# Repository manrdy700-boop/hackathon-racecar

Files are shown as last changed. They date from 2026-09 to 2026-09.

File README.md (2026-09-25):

# hackathon-racecar 🏆

北邮 & 中大四天三夜赛车黑客松（2026-08-26 ~ 08-29）**冠军车**的机械设计资料。

3D 打印底盘 + STM32 电控 + FPV 第一视角驾驶的迷你竞速车。四天内完成建模 → 打印 →
装配 → 调试 → 比赛全流程，最终在决赛夺冠（车手即本仓库作者）。

*Championship-winning mini FPV race car from a 4-day hackathon — mechanical design
files, printable STLs, gear-train calculators and build documentation. (Docs in Chinese.)*

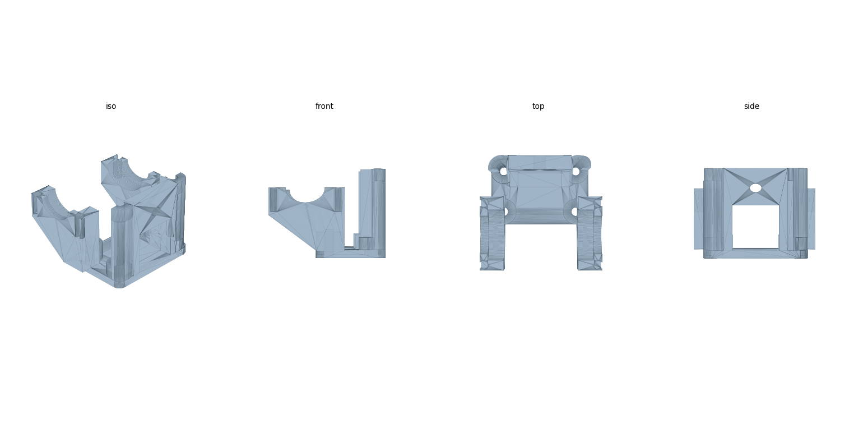
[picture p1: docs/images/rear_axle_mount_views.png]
后轴承座四视图


## 仓库内容

| 目录 | 内容 |
|---|---|
| `stl/` | 全套可打印 STL：前桥、后桥、轮辐盘（见下方零件清单） |
| `docs/机械结构说明书.pdf` | 差速器 / 传动 / 悬挂三大系统的原理与装配说明（含矢量示意图） |
| `docs/team/` | 团队文档模板：分工表、每日调试日志、赛道测试与调参记录、道具赛机制设计、差速器装配流程 |
| `tools/` | 齿轮传动计算器（Python）与说明书 PDF 生成脚本 |

## 零件清单

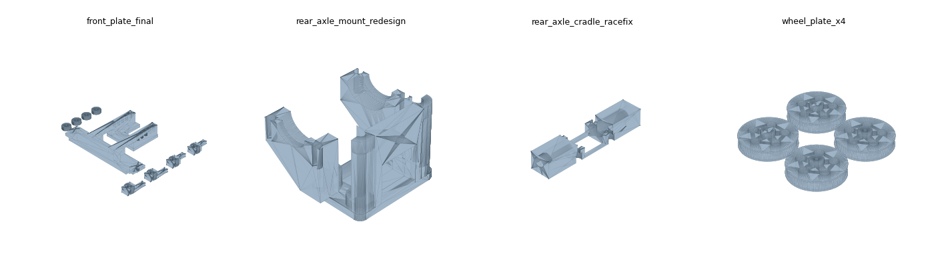
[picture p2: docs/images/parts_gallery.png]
零件总览


| 文件 | 说明 |
|---|---|
| `front_plate_final_0828.stl` | **前桥打印板（最终定稿版）**：主框架 + 转向节 + 轮毂盘，刚性结构 + 顶丝锁 + 销槽转向 |
| `rear_axle_mount_redesign.stl` | **后轴承座（重设计版）**：半圆轴承窝 + 侧导轨 |
| `rear_axle_cradle_racefix.stl` | 后轴托架 —— 比赛日凌晨 2:10 的抢修件，赛场应急设计的纪念 |
| `wheel_plate_x4.stl` | 轮辐盘 ×4 打印板 |
| `iterations/` | 被最终版取代的历史迭代（前桥 v1/v5、后轴承座旧版），保留供参考设计演进 |

打印参数：PLA，所有孔按名义尺寸 +0.25 mm 补偿设计（宁松勿紧，松了用顶丝锁）。

## 关键设计参数

| 项目 | 数值 |
|---|---|
| 齿轮模数 | 0.5 |
| 传动方案 | 单级减速，电机 8T 小齿 → 差速器 29T 盘齿 |
| 传动比 | 3.625（中心距 9.25 mm） |
| 车轮直径 | 28.14 mm |
| 理论极速 | ≈ 5.3 m/s (19 km/h) |
| 电机 | 有刷 13000 rpm / 28 g·cm / 7.0 V |
| 打印孔径补偿 | 名义尺寸 +0.25 mm（PLA，宁松勿紧，松了用顶丝锁） |

## 齿轮计算器用法

```bash
# 双联齿轮多级传动链：极速 / 加速度 / 每级中心距 / 编码器换算
python tools/gear_train.py --pinion 8 10 --compound 30:9 --final 29 --wheel 28.14

# 独立齿轮两两啮合的单级/两级方案枚举
python tools/gear_calc.py --tip-dia 15 16 9 17 --wheel 28.14
```

计算器会按「分度圆 d = m·z、中心距 a = m(z₁+z₂)/2」把齿数配对换算成整车极速、
起步加速度和建模打孔用的中心距，并给出室内小赛道的可用性判断。

## 经验教训（写给下一届）

- **打印队列是全营最大的瓶颈**——Day1 晚上必须交出切片，建模宁可保守也别返工
- **卡尺量到的是齿顶圆不是分度圆**，差 2 个齿 = 0.5 mm 中心距误差，足以卡死；数齿数核对
- **所有孔画名义 +0.25 mm**，锚点选前后轮毂；松了可以顶丝锁，紧了只能重打
- **耐力赛强制换胎** → 快拆车轮机构在 Day1 建模时就要设计进去
- 红外计时传感器和图传天线必须装车顶朝正上方，被车壳挡住就计不了圈

## 说明

- 车端固件基于主办方提供的 GT_Car 模板（STM32F103RCT6 + FreeRTOS）开发，
  模板版权归主办方，故固件代码不在本仓库内；本仓库仅包含我们自己的设计产出。
- SolidWorks 源文件由队友持有，本仓库提供打印用 STL。

## License

[MIT](LICENSE) — 随意使用、修改、商用，保留署名即可。

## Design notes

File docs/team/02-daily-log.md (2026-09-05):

# 每日调试日志

> 评分占比 10% 的「过程复盘与文档」主要看这份。每天收工前花 10 分钟填完，
> 不要攒到最后一天补——补出来的日志一眼就能看出来，而且真正的技术细节那时已经忘了。
>
> **填写要点**：问题记录写「现象 → 怎么定位 → 根因 → 怎么解决」，
> 不要只写「电机不转，后来好了」。根因那一栏是最值钱的，结营答辩和报告全靠它。

---

## Day1（8/26）理论认知 + 3D 建模设计

**当日目标**：出无干涉三维模型 → 切片 → 进打印队列；确定分工；搭好开发环境

| 时段 | 计划 | 实际完成 | 状态 |
|---|---|---|---|
| 09:00-09:40 | 开营宣讲 | | ☐ |
| 09:50-12:00 | 基础理论授课 | | ☐ |
| 14:00-18:00 | SolidWorks 建模 | | ☐ |
| 19:00-22:00 | 导出 STL / 切片 / 提交打印 | | ☐ |

**硬性产出物**

- ☐ 无干涉 SolidWorks 三维底盘模型
- ☐ 打印切片文件（含参数：层高 ___ / 填充率 ___ / 壁厚 ___ / 支撑 ___）
- ☐ 小组分工表
- ☐ 手绘整车电路接线草图
- ☐ 开发环境搭好，GT_TEST 能编译出 hex

**向主办方确认的问题与答复**

| 问题 | 答复 | 影响 |
|---|---|---|
| 车轮/轮胎从哪来？耐力赛的「胎」是什么 | | |
| 3D 打印机型号 / 台数 / 每组配额 | | |
| 红外传感器 + 图传天线尺寸与安装方式 | | |
| 电池规格 / 充电器 | | |
| 电机驱动芯片型号 | | |
| 编码器线数 | | |
| 方向盘可用按键 → 协议字段映射 | | |

**问题记录**

| # | 现象 | 定位过程 | 根因 | 解决方案 | 耗时 |
|---|---|---|---|---|---|
| 1 | | | | | |
| 2 | | | | | |

**当日复盘**

- 做得好的：
- 出问题的：
- 建模缺陷 / 次日修改方案：

**明日计划**：

---

## Day2（8/27）机械装配 + 硬件接线

**当日目标**：整车装配完成；接线无短路；电机与舵机能单独动起来

| 时段 | 计划 | 实际完成 | 状态 |
|---|---|---|---|
| 08:30-10:00 | 打印件取件、打磨修边 | | ☐ |
| 10:00-14:00 | 整车机械组装 | | ☐ |
| 14:00-18:00 | 电控硬件接线 | | ☐ |
| 19:00-23:00 | 环境搭建 + 分模块调试 | | ☐ |

**硬性产出物**

- ☐ 完整装配的机械整车
- ☐ 标准化电路接线图
- ☐ 电机/舵机单模块调试代码（可运行）
- ☐ 跨小组互查机械结构与电路隐患（互查组：____）

**上电前安全检查**（PPT 明确要求，每次上电都要走一遍）

- ☐ 电池正负极正确
- ☐ 板上无锡球、无导体杂质
- ☐ 无机械卡死 / 堵转
- ☐ 万用表通断检测：电源对地不短路

**标定记录**（数值同步填进 `User/Task/car_config.h`，并记到 `03-track-test-log.md`）

| 参数 | 实测值 | 怎么测的 |
|---|---|---|
| `MOTOR_DEADZONE` | | 车架空，油门从 0 慢加，记轮子刚转的 PWM |
| `MOTOR_REVERSE` | | 前进方向是否正确 |
| `SERVO_TRIM` | | 直行时车不跑偏的中位补偿 |
| `SERVO_HALF_RANGE` | | 加到轮子打满但拉杆不顶死 |
| `SERVO_REVERSE` | | 打左是否真的往左 |
| `ENCODER_DIR` | | 前进时速度是否为正 |
| `COUNTS_PER_METER` | | 推车走 1 米的总计数（推 3 次取平均） |

**问题记录**

| # | 现象 | 定位过程 | 根因 | 解决方案 | 耗时 |
|---|---|---|---|---|---|
| 1 | | | | | |
| 2 | | | | | |

**当日复盘**：

**明日计划**：

---

## Day3（8/28）整车联调 + 赛道迭代测试

**当日目标**：FPV 能开；跑完适应性路段；锁定最终调校参数

| 时段 | 计划 | 实际完成 | 状态 |
|---|---|---|---|
| 08:30-12:00 | 整车软硬件联调 + 图传 | | ☐ |
| 14:00-18:30 | 绕桩 / 起伏 / 8 字专项测试 | | ☐ |
| 19:00-24:00 | 迭代调参 + 全量故障排查 | | ☐ |

**硬性产出物**

- ☐ 整车联动控制程序
- ☐ 赛道测试记录表（见 `03-track-test-log.md`）
- ☐ 参数优化迭代日志（同上）
- ☐ **三维模型与完整控制代码已备份**（git commit + 云盘/U 盘）
- ☐ 三人都完成驾驶练习，记录各自平均圈速
- ☐ 耐力赛换胎流程演练并计时

**问题记录**

| # | 现象 | 定位过程 | 根因 | 解决方案 | 耗时 |
|---|---|---|---|---|---|
| 1 | | | | | |
| 2 | | | | | |

**当日复盘**：

**明日备战清单**：

---

## Day4（8/29）性能考核 + 竞速总决赛

**赛前检查**（每场比赛前都走一遍）

- ☐ 电池电压 > 7.4V（低于 6.6V 必须换/充）
- ☐ 图传天线、红外传感器朝正上方且无遮挡
- ☐ 螺丝无松动、结构无开裂
- ☐ 车轮无旷量、转向无卡顿
- ☐ 遥控链路正常（心跳灯慢闪 = 正常，快闪 = 失联）
- ☐ 备件与工具已带到赛道边

**成绩记录**

| 比赛 | 时间 | 成绩 | 名次 | 问题/备注 |
|---|---|---|---|---|
| 排位赛（最快单圈） | 10:00 | | | |
| 15 圈正赛 · 小组赛 | 11:00 | | | |
| 15 圈正赛 · 决赛 | | | | |
| 道具赛 · 小组赛 | 14:00 | | | |
| 道具赛 · 复活/半决/决赛 | | | | |
| 耐力赛 · 小组赛 | 15:00 | | | |
| 耐力赛 · 后续轮次 | | | | |

**结营总结要点**

- 最大的技术难点：
- 最有效的一次优化：
- 如果重来一次会怎么做：

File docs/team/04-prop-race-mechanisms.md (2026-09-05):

# 道具竞速赛 · 机制方案设计

> **规则**（PPT P9）：15 圈，可使用**最多 3 种机制**，每种**不超过 5 次**，
> 每次**不超过 3 秒**，**机制需绑定方向盘按键**。
> 说明原文：「附加题，发散思维，尽可能干扰对手 or 帮助自己」。

---

## 一、一个漂亮的对应关系

主办方的通信协议（`User/Bsp/ControlToCar.pb.h` → `CarData_Function`）里，
方向盘能下发的**布尔型按键字段正好是 3 个**：

| 协议字段 | 原设计用途 | 我们拿来做 |
|---|---|---|
| `c_signal` | 电容 / ERS 放电 | 机制 A |
| `battle_signal` | 缠斗 / DRS | 机制 B |
| `drift` | 漂移开关 | 机制 C |

**3 个 bool 按键 ↔ 规则允许的 3 种机制**，不需要改通信协议，也不需要主办方配合改地面站。
读法就是 `rc_ctrl.car_function.c_signal` 等，通信任务已经解析好了。

> ⚠️ **开营后必须确认的一件事**：方向盘上到底哪几个物理按键映射到这三个字段？
> 如果地面站现在把 `c_signal` 硬编码成 0（完整版固件的文档 §4.1 提到过这个情况），
> 那这条路就不通，要请主办方打开。**这个问题今天就要问。**

---

## 二、核心工程点：把规则写进固件

**不要靠车手手动松手来控制 3 秒。** 手一抖按成 3.2 秒就可能被判违规，
而且没人数得清用了几次。正确做法是写一个**机制管理器**，由固件强制保证：

- **上升沿触发** —— 按住不放只算一次，松开再按才是第二次
- **满 3 秒自动截断** —— 物理上不可能超时
- **每种用满 5 次后自动失效** —— 物理上不可能超次
- **冷却时间** —— 防手抖连点白白浪费次数
- **失联 / 低压时强制关闭** —— 安全兜底

这段代码本身就是很好的答辩材料：**「我们把比赛规则编译进了固件，所以我们不可能违规」**。

### 实现状态

| 机制 | 绑定按键 | 状态 |
|---|---|---|
| A · 弹射起步 Boost | `c_signal` | ✅ 已实现 (`User/Task/mech.c`) |
| B · 出弯循迹控制 TC | `battle_signal` | ✅ 已实现 (`User/Task/mech.c`) |
| C · 爆闪 / 机械挡板 | `drift` | ⏳ 次数与时长约束已生效, 输出待硬件确定 |

代码在 `User/Task/mech.c` / `mech.h`, 参数在 `car_config.h` 第 8 节。
下面保留设计说明, 便于答辩时讲清楚思路。

### 参考实现

放在 `chassis_task.c` 里，`Chassis_Loop()` 每 1ms 调用一次即可。

```c
/* ---- 道具赛机制管理器 ---- */
#define MECH_MAX_USE       5      /* 规则: 每种最多 5 次 */
#define MECH_MAX_MS     3000      /* 规则: 每次最长 3 秒 */
#define MECH_COOLDOWN_MS  500     /* 冷却, 防手抖连点浪费次数 */

typedef enum { MECH_BOOST = 0, MECH_TC, MECH_STROBE, MECH_COUNT } MechId_t;

typedef struct {
    uint8_t  active;         /* 当前是否生效 */
    uint8_t  used;           /* 已使用次数 */
    uint32_t start_tick;     /* 本次激活时刻 */
    uint32_t last_end_tick;  /* 上次结束时刻(冷却用) */
    uint8_t  key_prev;       /* 上一拍按键电平(上升沿检测用) */
} Mech_State_t;

static Mech_State_t mech[MECH_COUNT];

static void Mech_Update(MechId_t id, uint8_t key)
{
    Mech_State_t *m = &mech[id];
    uint32_t now = HAL_GetTick();

    /* 失联时一律强制关闭, 不允许任何机制残留 */
    if (rc_ctrl.RC_READY != 0)
    {
        if (m->active) { m->active = 0; m->last_end_tick = now; }
        m->key_prev = key;
        return;
    }

    if (m->active)
    {
        if (now - m->start_tick >= MECH_MAX_MS)      /* 到时自动截断 */
        {
            m->active = 0;
            m->last_end_tick = now;
        }
        else if (!key)                                /* 提前松手 */
        {
            m->active = 0;
            m->last_end_tick = now;
        }
    }
    else
    {
        /* 上升沿 + 还有次数 + 过了冷却 */
        if (key && !m->key_prev
            && m->used < MECH_MAX_USE
            && (now - m->last_end_tick) >= MECH_COOLDOWN_MS)
        {
            m->active     = 1;
            m->used++;
            m->start_tick = now;
            TIM4->CCR1 = BEEP_CCR;      /* 短鸣一声, 车手能听见"生效了" */
        }
    }
    m->key_prev = key;
}

/* 在 Chassis_Loop() 开头调用 */
static void Mech_Poll(void)
{
    Mech_Update(MECH_BOOST,  rc_ctrl.car_function.c_signal);
    Mech_Update(MECH_TC,     rc_ctrl.car_function.battle_signal);
    Mech_Update(MECH_STROBE, rc_ctrl.car_function.drift);
}
```

**次数复位**：每场比赛开始前要把 `used` 清零。三种做法，按优先级：
1. 地面站的 `rc_ctrl.car_status.race_mode` 有变化时清零（最干净，需确认地面站会不会发）
2. 板载按键 `PA1` 长按 2 秒清零（自己可控）
3. 每场比赛前重新上电（最笨但一定有效）

**车手反馈**：车就在同一个场地里，蜂鸣器是听得见的。约定：
激活时短鸣一声，第 5 次（最后一次）激活时鸣两声，用完后再按不响 —— 车手就知道没了。

---

## 三、三种机制的候选方案

按**实现风险**分三档。选择原则很重要：

> **道具赛只是四场比赛之一，而正赛和耐力赛是主分。**
> 任何会提高故障率的机制都是负收益 —— 一个卡住的机械挡板可能让你整场退赛。
> 建议配置：**2 个纯软件机制 + 最多 1 个硬件机制**。

### ✅ 机制 A：弹射起步 / Boost（自己增益）— 纯软件，强烈推荐

绑 `c_signal`。3 秒内：

- 强制解除档位限速（`gear_scale` 视为 1.0）
- `MOTOR_SLEW_PER_MS` 临时提高到 400（响应更快，代价是可能打滑）
- 油门系数 ×1.25，但 PWM 仍然硬限幅在 9999

**用途**：发车瞬间、长直道超车。

**必须带的保护**：电流冲击会把母线电压拉低，可能导致图传或主控重启（直接退赛）。
所以加一条：`if (chassis_measure.VBUS < 6.8f) 自动退出 Boost;`
这个细节写进报告很加分——说明你们真的想过副作用。

```c
if (mech[MECH_BOOST].active && chassis_measure.VBUS > 6.8f)
{
    ratio = ((fp32)throttle / 100.0f) * 1.25f;   /* 无视档位限速 */
    if (ratio > 1.0f) ratio = 1.0f;
}
```

### ✅ 机制 B：出弯循迹控制 TC（自己增益）— 纯软件，强烈推荐

绑 `battle_signal`。3 秒内检测驱动轮打滑并自动回油。

**打滑判据**（有编码器就能做）：油门在涨、PWM 在涨，但 `v_measure` 不涨甚至在抖 →
说明轮子在空转。此时把 PWM 乘 0.85，等速度重新跟上来再放开。

**用途**：出弯地板油。对手打滑空转的时候你在加速，一个弯就能拉开半个车身。

**为什么推荐**：纯软件、零硬件风险、真正有工程含量、答辩时好讲，
而且它用到了你们自己写的编码器测速——是整条电控链路的成果展示。

### ⚠️ 机制 C-1：爆闪干扰（干扰对手）— 需要额外硬件

绑 `drift`。3 秒内车尾大功率 LED 以约 10Hz 闪烁。

**原理**：所有人都是靠 FPV 摄像头驾驶的。摄像头有自动曝光，
被强光反复冲击时画面会一明一暗剧烈跳变，后车短时间内基本没法判断路线。
PPT 举例里写的「爆闪」应该就是指这个。

**实现**：不要用 GPIO 死循环翻转（会占 CPU），用一个 PWM 通道或在 1000Hz 循环里用时间戳翻转。

**需要的东西**：大功率 LED + MOSFET 驱动（板上小状态灯 PB8/PB9 亮度完全不够，
只能当指示，不能当武器）。这些**不在物资清单里，要申请或自备**。

> 🔴 **两个必须先问清楚的点**：
> 1. **会不会干扰计时？** 车顶那个红外传感器是比赛计时用的。如果 LED 有红外分量，
>    可能干扰自己或别人的计时系统 —— 那就不是「干扰对手」而是「破坏赛事设备」了。
>    **选纯可见光 LED，避开红外波段**，并且事先跟主办方确认。
> 2. **规则允许到什么程度？** 亮度有没有上限？直射对手算不算犯规？

### ⚠️ 机制 C-2：机械阻挡板（干扰对手）— 需要第二个舵机 + 今天就要建模

绑 `drift`。3 秒内舵机把一块挡板/扰流板展开，占据赛道内线宽度，逼后车减速或走外线。

**可行性（我查过工程了）**：
- 舵机配额是 **≤3 个**，转向只用了 1 个，**还有 2 个可用**
- 软件上：`TIM1_CH2/CH3/CH4`（PA9 / PA10 / PA11）目前**都没被占用**
  （USART1 没有初始化，TIM1 只配了 CH1），而且它们和转向舵机**共用同一个 50Hz 时基**，
  CCR 换算完全一样 —— 加第二个舵机在软件上几乎是免费的
- ⚠️ 但**必须确认这几个引脚在板子上有没有引出来**，这个只能看实物/原理图，我没法从代码判断

**🔴 时间敏感**：如果要做这个机制，**今天下午建模就必须预留第二个舵机的安装位和挡板的运动空间**。
明天再想加就来不及了 —— 底盘已经打印完了。**这是现在唯一需要立刻通知队友的事。**

### 其它可选（低成本备选）

- **鸣笛干扰**：蜂鸣器长鸣。零成本、零风险，但效果基本是心理层面的，建议只作为凑数的第三个机制。
- **假动作**：3 秒内故意让状态灯常亮，配合走位骗对手以为你要放大招。趣味性大于实用性。

---

## 四、推荐配置

| 机制 | 绑定按键 | 类型 | 硬件需求 | 风险 |
|---|---|---|---|---|
| A · 弹射起步 Boost | `c_signal` | 自己增益 | 无 | 低（带低压保护） |
| B · 出弯循迹控制 TC | `battle_signal` | 自己增益 | 无 | 无 |
| C · 爆闪 **或** 挡板 | `drift` | 干扰对手 | 有 | 中 |

**A 和 B 今晚就能写完并且不依赖任何硬件**，建议先把这两个做出来，
C 等确认了主办方的规则口径和硬件供应再定。

---

## 五、待确认清单

- ☐ 方向盘上哪些按键映射到 `c_signal` / `battle_signal` / `drift`？地面站会不会真的发出来？
- ☐ 机制的「使用次数」由谁统计？裁判人工数，还是要我们回传？
- ☐ 爆闪是否允许？亮度有无限制？会不会干扰红外计时？
- ☐ 机械阻挡是否允许？展开尺寸有无限制？
- ☐ 每场比赛之间是否重新上电（决定次数复位怎么做）？
- ☐ `TIM1_CH2/CH3/CH4`（PA9/PA10/PA11）在板子上有没有引出？

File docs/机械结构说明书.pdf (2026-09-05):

# 整车动力链路

从电机到车轮，动力怎么一步步传过去

先建立整体印象。你手上的所有传动件，都是下面这条链路上的一环：

传动比 = 29 / 8 = 3.625 极速约 5.3 m/s (19 km/h) 电机小齿与差速器盘齿的中心距 = 0.5 x (8 + 29) / 2 = 9.25 mm

### 三个子系统各管什么

差速器 —— 让左右轮在过弯时能有不同转速，否则内侧轮必然拖地打滑 传动机制 —— 把电机的高转速低扭矩，换成车轮要的低转速高扭矩 悬挂 —— 在颠簸和过弯时把轮胎按在地面上，没有抓地力一切都是空谈

### 一句话记住它们的关系

传动决定“跑多快”，差速决定“弯里顺不顺”，悬挂决定“力能不能真的传到地上”。

### 怎么用这份文档

第 2~4 页各讲一个子系统：原理 -> 结构图 -> 装配要点
第 5 页是零件对照表和装配顺序，动手时照着走
图是示意图，不是装配图 —— 具体件的细节以实物和驻场导师为准

### 已经定下来的参数

车轮直径 28.14 mm | 差速器盘齿 29T (待数齿确认)
电机小齿 8T | 传动比 3.625 | 中心距 9.25 mm
齿轮模数 m = 0.5 | 电机 13000 rpm / 28 g·cm

传动比一旦改动，车速、加速度和电控里的 COUNTS_PER_METER 都要跟着重算。

# 一、差速器

你手上这个是成品总成，不用拆装

### 为什么需要它

过弯时，外侧轮走的弧线比内侧长，所以外侧必须转得更快。 如果左右轮硬连在一根轴上，过弯时一定有一个轮在地上蹭 —— 既慢又容易失控。

### 内部结构

盘齿(29T) — 电机的动力从这里进来

左输出 | 右输出

行星齿轮 — 跟壳体公转, 过弯时才自转
半轴齿轮 — 接左右输出
十字轴 — 行星齿轮套在它上面

### 它是怎么工作的

直线跑：左右阻力相同 → 行星齿轮不自转，只跟着壳体公转 → 左右同速 过弯时：一侧阻力大 → 行星齿轮开始自转 → 一侧减速，另一侧同等加速

关键性质：左右轮的转速之和恒等于壳体转速的两倍。所以只要一侧悬空， 动力就会全跑到那一侧 —— 这是开放式差速器的固有缺点，起步别急给油。

### 装到车上要注意

两端的轴承坐进底盘的轴承座，必须同轴，歪了会异响和卡滞 盘齿与电机小齿的中心距 9.25mm，误差控制在 ±0.05mm 啮合不能太紧(卡死、烧电机)也不能太松(打齿)，装好用手转应顺滑无卡点

# 二、传动机制

减速齿轮组 + 万向节传动轴

### 为什么要减速

电机转速 13000rpm、扭矩只有 28 g·cm —— 转得飞快但没力气。 直接接轮子的话，车会以 70+ km/h 的理论速度起步，而实际扭矩根本推不动。 齿轮减速就是拿转速换扭矩：转速降到 1/3.625，扭矩放大 3.625 倍。

### 模数与中心距 — 建模打孔必须用这两条公式

分度圆直径 d = m x z (m = 模数 = 0.5，z = 齿数)
中心距 a = m x (z1 + z2) / 2

注意：卡尺量到的是齿顶圆 d顶 = m(z+2)，不是分度圆。两者差 2 个齿， 折算到中心距是 0.5mm 误差 —— 足以让齿轮卡死或打齿。要数齿数核对。

### 万向节传动轴 — 为什么不能用一根直轴

差速器 | 轮轴

悬挂上下运动时
这两端可以摆动

球头 / 万向节

车轮装在悬挂上，会相对车身上下运动；差速器固定在底盘上，不动 两者之间的距离和角度一直在变，直轴会别死 —— 所以要用带球头的万向节 你手上那两根带球头的金属组件就是它，左右各一根

### 装配要点

球头两端都要能自由摆动，装好后手动上下扳一扳确认不卡 传动轴长度要与悬挂行程匹配：压缩到底和完全伸展时都不能脱出或顶死 这是全车受力最大的零件之一，装配后每天检查一次有没有旷量变大

# 三、悬挂

导向轴 + 弹簧 = 滑柱式悬挂

### 它要解决什么

赛道有起伏。轮子一旦离地，抓地力归零 —— 动力、刹车、转向全部失效。 悬挂的唯一任务：不管路面怎么颠，把四个轮子始终按在地上。

### 你手上这套是最简单也最可靠的一种

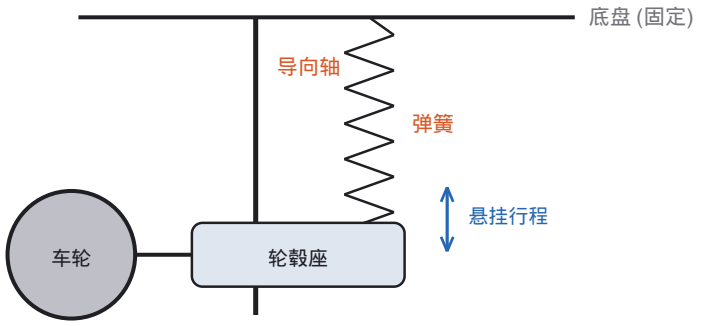
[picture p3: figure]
导向轴; 轮毂座; 悬挂行程

### 工作方式

轮毂座套在导向轴上，只能沿轴上下滑动，不会前后左右晃 弹簧被压缩后产生回弹力，把轮子往地面推
路面凸起 → 轮子上抬压缩弹簧；路面凹陷 → 弹簧伸展把轮子推下去

### 三个要调的参数

行程 —— 上下能走多远。太小容易触底，太大车身会晃、重心转移过多 预压 —— 装配时弹簧已被压缩的量。预压越大悬挂越硬、响应越快但越颠 刚度 —— 弹簧本身的软硬。前后可以配不同刚度来调转向特性

经验起点：静止时悬挂压缩掉总行程的 1/4 到 1/3，剩下的留给路面起伏。 完全压不动 = 太硬(等于没悬挂)；一放上去就压到底 = 太软(过弯会触底)。

### 装配要点

导向轴必须垂直于底盘，歪了会卡滞甚至完全动不了
装好后用手压轮子，应能顺滑上下且自己弹回原位，无卡点、无异响 左右两侧的预压必须一致，否则车会自动往一边跑

# 四、零件对照与装配顺序

把手上的件对上号

### 零件用途对照

差速器总成 (含轴承) | | 后桥核心，成品，不用拆
万向节传动轴 | | 差速器 -> 左右轮
大齿轮 / 小齿轮 | 若干 | 减速齿轮组，本方案只用 8T + 差速器盘齿
轴承 | ~8 | 差速器 2、轮轴 4、其余备用
弹簧 | ~6 | 悬挂，每轮一根
直金属轴 | ~8 | 导向轴(悬挂) / 轮轴
球头螺柱 | ~6 | 转向拉杆、悬挂连杆

### 建议装配顺序

1. 差速器压进底盘轴承座 —— 先确认两个座同轴
2. 装电机 + 8T 小齿 —— 调整到与盘齿啮合顺滑，中心距 9.25mm
3. 装悬挂：导向轴穿轮毂座，套弹簧，两侧预压对称
4. 装万向节传动轴 —— 连接差速器与轮轴，上下扳动确认不卡
5. 装转向：舵机 + 球头拉杆，确认左右打角对称
6. 整车手动推行一圈 —— 无卡滞、无异响才能上电

### 上电前最后检查 (PPT 强制要求)

用手转动传动系统一整圈，确认没有任何机械卡死
电池正负极正确，板上无锡球、无导体杂质
万用表测电源对地不短路

本文档为通用结构说明，具体件的装配细节以驻场导师和实物为准。

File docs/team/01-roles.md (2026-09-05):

# 小组分工表

> Day1 硬性产出物。填完打印/截图交给导师，同时留档进项目报告。

## 一、基本信息

| 项目 | 内容 |
|---|---|
| 组号 | |
| 车辆 ID（1~8） | |
| 2.4G 频道（= ID × 15） | |
| 队名 | |

## 二、成员与固定分工

| 姓名 | 角色 | 主要职责 | 联系方式 |
|---|---|---|---|
| | **结构工程师** | SolidWorks 建模、底盘/悬挂/转向结构设计、3D 打印管控、整车机械装配 | |
| | **电控工程师** | STM32 主控、电机/舵机驱动、编码器测速、图传接线、底层控制代码编写与调试 | |
| | **测试运维** | 赛道试跑、性能记录、故障排查、参数迭代优化、比赛数据记录 | |

## 三、每日轮换计划

> 手册要求：「每晚开展组内复盘，轮换辅助操作，全员掌握机械+电控基础操作」。
> 轮换不是换主责，是每晚抽 30~60 分钟让另外两人上手一次。

| 日期 | 轮换内容 | 由谁带 | 谁来练 | 完成 |
|---|---|---|---|---|
| Day1 晚 | SolidWorks 基本操作 / 切片参数设置 | | | ☐ |
| Day2 晚 | 万用表通断检测 / 烧录与串口调试 | | | ☐ |
| Day3 晚 | 驾驶练习（三人都必须练，耐力赛要用） | | | ☐ |

## 四、耐力赛车手排班 ⚠️

> **规则推导**（很多组会读错，先对齐）：
> - 全场 20 圈，**必须完成 2 次换胎**，换胎同时**必须更换车手** → 全程正好分成 **3 个赛段**
> - 每次进站都要换人 ⇒ 相邻赛段不能是同一人
> - **每位车手驾驶圈数 ≥ 3 圈** ⇒ 如果只有 2 个人开，第三人 0 圈，直接违规
> - **结论：三名队员必须全部上场，每人至少 3 圈，三段圈数之和 = 20**

**排班表**（最快的车手放最长赛段）：

| 赛段 | 车手 | 圈数 | 备注 |
|---|---|---|---|
| 第 1 段（起步） | | | 起步位重要，放稳的人 |
| 第 2 段 | | | |
| 第 3 段（冲刺） | | | |
| **合计** | | **= 20** | |

> 参考分法：`7 / 7 / 6`（均衡）或 `3 / 3 / 14`（把绝大部分圈数给最快车手，但风险是他中途出错就没法补救）。
> **Day3 晚练车时记录三人的平均圈速，再定这张表。**

**换胎分工**（进站时间直接算进成绩，Day3 晚务必演练计时）：

| 动作 | 负责人 | 目标耗时 |
|---|---|---|
| 接车 / 固定车身 | | |
| 拆装车轮 | | |
| 车手交接（接管方向盘） | | |
| 放车 / 喊出发 | | |
| **进站总耗时目标** | | **< 20s** |

## 五、关键决策记录

> 做了什么选择、为什么。写报告时直接抄这里。

| 日期 | 决策事项 | 选择 | 理由 |
|---|---|---|---|
| Day1 | | | |
| | | | |

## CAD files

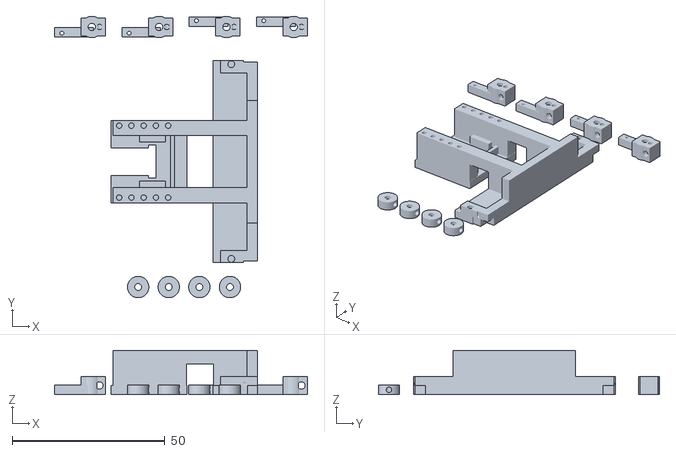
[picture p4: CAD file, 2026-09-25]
stl/front_plate_final_0828.stl
82.7 x 92.0 x 14.5

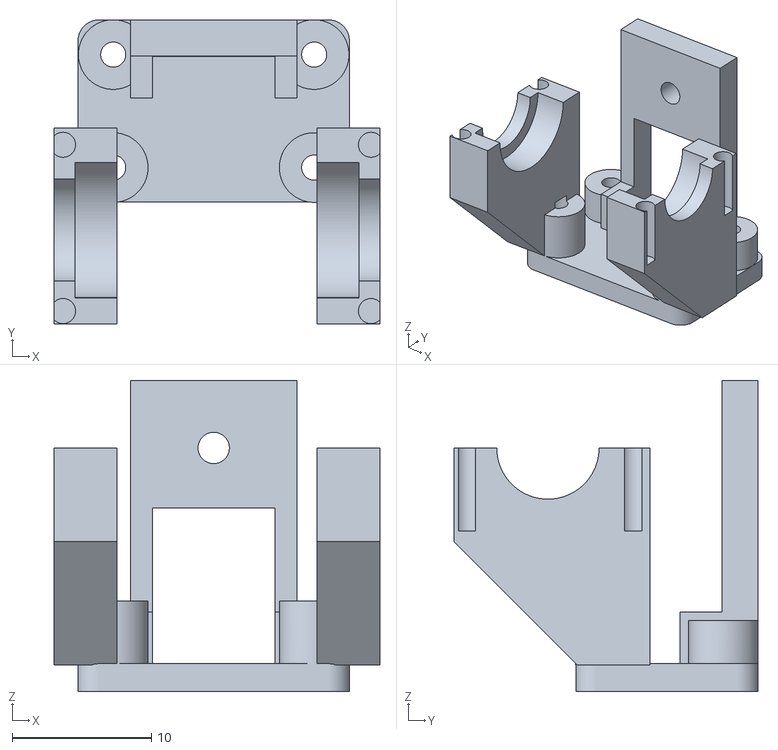
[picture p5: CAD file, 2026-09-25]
stl/iterations/rear_axle_support_A.stl
23.4 x 21.9 x 22.4

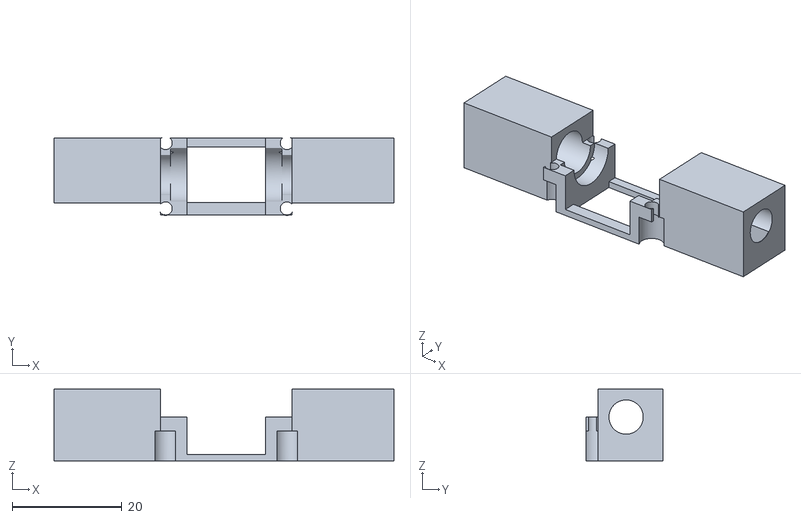
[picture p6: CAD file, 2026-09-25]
stl/rear_axle_cradle_racefix.stl
62.1 x 14.1 x 13.1

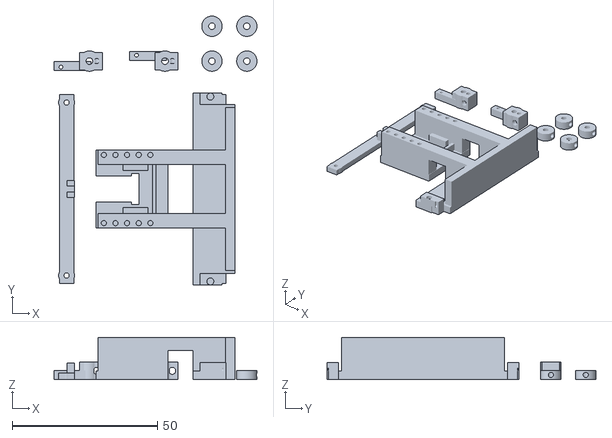
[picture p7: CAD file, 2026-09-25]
stl/iterations/front_plate_v5_0827.stl
69.8 x 92.5 x 14.5

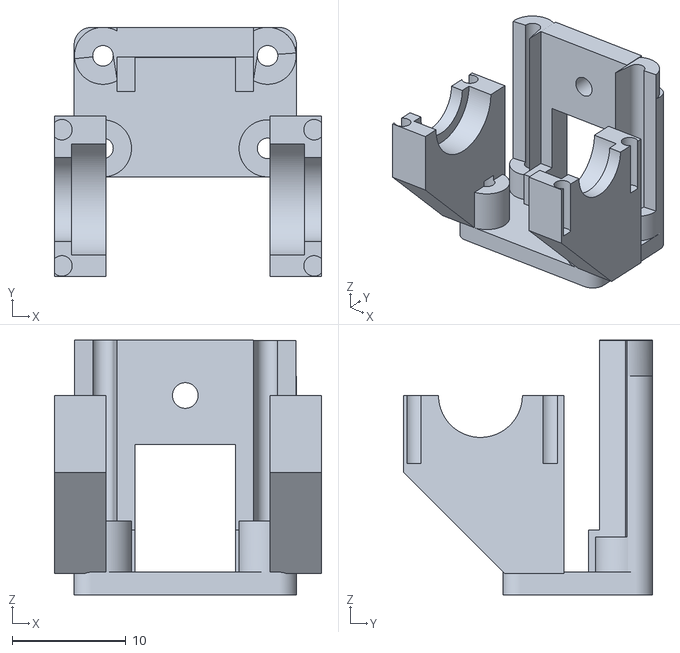
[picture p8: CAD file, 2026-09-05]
stl/rear_axle_mount_redesign.stl
23.4 x 21.9 x 22.4

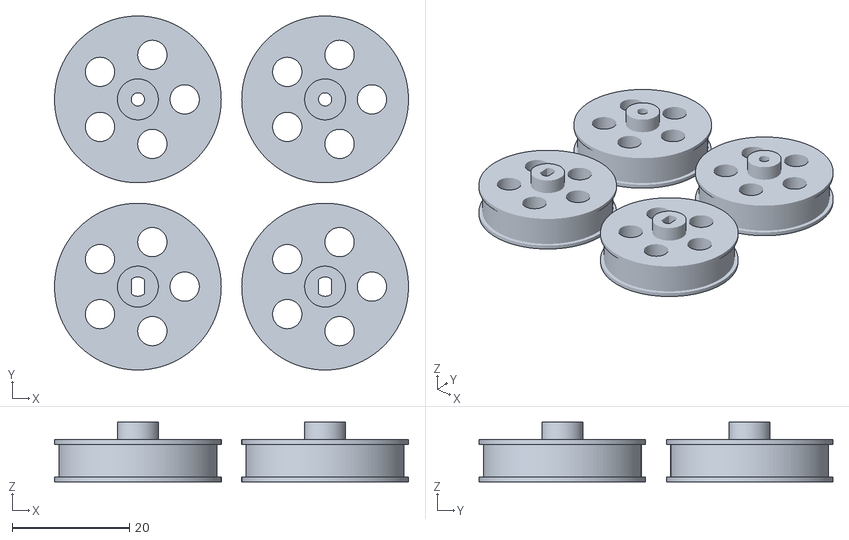
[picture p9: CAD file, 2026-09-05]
stl/wheel_plate_x4.stl
60.5 x 60.5 x 10.2

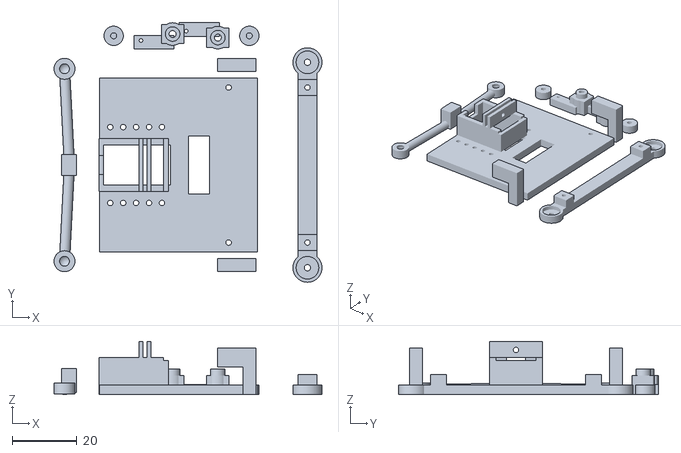
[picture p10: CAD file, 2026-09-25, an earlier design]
stl/iterations/front_plate_v1_0827.stl
83.0 x 80.3 x 16.5

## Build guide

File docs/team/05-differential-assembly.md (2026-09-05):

# 差速器装配流程

> ⚠️ **这份是通用流程，不是本套件的官方说明书。**
> 我没法从照片认出这个差速器的具体型号，网上也搜不到对应教程。
> 但小型 RC 塑料差速器的结构是高度标准化的，下面的流程适用于绝大多数。
>
> **最快的权威答案有三个来源**（都比看这份文档快）：
> 1. **问驻场导师** —— 手册写了夜间有轮值导师，他们见过这套件
> 2. **让队友用 SolidWorks 打开 `差速器.SLDPRT`** —— 零件包里就有，能直接看到形状
> 3. **看 PPT 第 3 页的底盘参考照片** —— 上面有装好的整车

---

## 一、先理解它为什么长这样

差速器解决一个问题：**过弯时外侧轮要比内侧轮转得快**。如果两个轮硬连在一根轴上，
过弯时必然有一个轮在打滑，既慢又费胎。

它的做法是：动力先进到一个**会整体旋转的壳体**上，壳体里横着一根轴，
轴上套着能自转的**行星齿轮**，行星齿轮同时咬住左右两个**半轴齿轮**。

- 直线跑：两侧阻力一样 → 行星齿轮不自转，只跟着壳体公转 → 左右同速
- 过弯：一侧阻力大 → 行星齿轮开始自转 → 一侧减速、另一侧同等加速

**理解这一点很重要**，因为装配的核心就是让行星齿轮和两个半轴齿轮**正确啮合**。
啮合错了，要么卡死，要么打齿。

---

## 二、认件

先把所有件从袋子里倒出来，**摊在白纸或浅色盘子上分类**，别在深色桌布上操作
（伞齿轮很小，掉了基本找不回来）。

| 件 | 长什么样 | 数量 |
|---|---|---|
| 差速器壳体 | 半透明塑料，通常是两半可以合起来，中间有容纳齿轮的空腔 | 1 组 |
| 盘齿（大齿轮） | 最大的那个白色直齿轮，会固定在壳体上 | 1 |
| 行星齿轮 | 小锥齿轮（伞齿），齿面是斜的 | 2 或 4 |
| 半轴齿轮 | 也是锥齿轮，通常比行星齿轮大一点，中间有方孔或花键 | 2 |
| 十字轴 / 一字轴 | 细金属轴，行星齿轮套在上面 | 1 |
| 输出杯 / 半轴 | 接传动轴的那两头 | 2 |
| 垫片 | 薄金属或塑料环，调间隙用（不一定有） | 若干 |

> **数量对不上就先别装。** 少一个行星齿轮会导致受力不均直接打齿。
> 对不上就去问导师要，别硬凑。

---

## 三、装配步骤

### 1. 放两个半轴齿轮
把两个半轴齿轮分别放进壳体左右两侧的位置，锥齿面朝内（朝向壳体中心）。

**检查**：两个齿轮应该能在各自的窝里自由转动，不卡。

### 2. 行星齿轮套上十字轴
把行星齿轮套到十字轴上。如果是 4 个行星齿轮，就是十字轴四个方向各一个；
如果是 2 个，用的是一字轴（直销），两端各一个。

### 3. 装进壳体中央
把「十字轴 + 行星齿轮」这个组件放进壳体中间，让**行星齿轮同时咬住左右两个半轴齿轮**。

⚠️ **这是整个装配最容易出错的一步。** 放进去之后：
- 十字轴的两端必须**完全落进壳体上对应的槽或孔里**，不能翘着
- 用手指轻拨行星齿轮，应该能自转，且带动两个半轴齿轮**反向**转动

没做到这两点就合壳，一定卡死。

### 4. 合上另一半壳体 / 装盘齿
把另一半壳体盖上。盘齿通常固定在其中一半壳体上（有的是一体的，有的用螺丝拧）。

### 5. 上螺丝 —— 对角、分次、均匀
**不要一颗拧到底再拧下一颗。** 按对角顺序，每颗先拧两圈，转一圈再拧紧。

- **拧太紧** → 壳体变形，内部齿轮被夹死，转不动
- **拧太松** → 跑起来散架

**边拧边用手转**，一旦感觉变紧或有卡点，立刻退回去检查。

### 6. 装输出杯 / 半轴
接上两侧的输出件。

### 7.（可选）润滑
塑料件抹一点点润滑脂能减少磨损和异响。**别抹多**，多了会甩到盘齿上粘灰粘碎屑。

---

## 四、验收测试 ⭐

装完必须做，三个测试都过了才算装对。

### 测试 1：差速功能（最关键）
**抓住盘齿不让它转**，用手转一侧输出轴。

- ✅ **正确**：另一侧输出轴**反方向**转，速度相同
- ❌ 另一侧不动 → 行星齿轮没咬上，或者卡死了
- ❌ 另一侧同方向转 → 装错了，内部结构不对

这是差速器的定义性行为，过了这一关基本就对了。

### 测试 2：同步
两只手同时把两侧输出轴**朝同一方向**转。

- ✅ **正确**：盘齿跟着一起转（此时行星齿轮不自转）

### 测试 3：顺滑度
慢慢转动盘齿一整圈。

- ✅ **正确**：全程顺滑、力度均匀、无异响
- ❌ 有周期性卡点 → 某处啮合不良或有异物
- ❌ 整体很紧 → 螺丝拧过头了，松一点重来

### 附加检查：轴向旷量
沿轴向推拉输出轴，应该只有极小间隙。旷量太大跑起来会异响、磨损快。

---

## 五、常见错误

| 现象 | 原因 | 怎么办 |
|---|---|---|
| 合不上壳 | 十字轴没坐进槽 | 拆开，把轴两端对准槽再合 |
| 装好后转不动 | 螺丝拧太紧 / 齿轮错位 | 先松螺丝试；还不行就拆开重装 |
| 转起来咔咔响 | 啮合不良、有毛刺或碎屑 | 拆开清理，检查齿面有没有飞边 |
| 转一侧另一侧不动 | 行星齿轮没啮合上 | 必须拆开重装，这个不能将就 |
| 跑一会就散 | 螺丝没拧紧 / 没上螺丝胶 | 拧紧；条件允许上一点螺丝胶 |

---

## 六、装完顺手做两件事

1. **数盘齿的齿数并记录** —— 这个数还没确定（外径 15.60mm 卡在 29T 和 30T 之间），
   它决定电机小齿到差速器的中心距是 **9.25mm 还是 9.50mm**，队友建模打孔要用。

2. **量三个尺寸给建模的人**：差速器总宽、输出轴直径、盘齿外径。

3. **拍照存档** —— Day1 调试日志和最终项目报告都要图，现拍比事后补容易。

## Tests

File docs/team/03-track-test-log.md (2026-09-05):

# 赛道测试与参数迭代记录

> Day3 的核心产出物。这份表同时承担两个作用：
> 1. **赛道测试记录表**（当日硬性产出）
> 2. **参数优化迭代日志**（评分里「迭代优化表现」的唯一证据）
>
> **铁律：一次只改一个参数。** 同时改两个，圈速变了你也不知道是哪个起的作用，
> 这一轮测试就白做了。

---

## 一、标定基准值

> Day2 装好车后先做完这一节，后面所有测试都建立在它之上。
> 数值同步写进 `User/Task/car_config.h`。

| 参数 | 标定值 | 标定方法 | 日期 |
|---|---|---|---|
| `MOTOR_DEADZONE` | | 车架空，油门缓加，记轮子刚开始转的 PWM | |
| `COUNTS_PER_METER` | | 地面量 1 米，手推车走完读总计数，推 3 次取平均 | |
| `SERVO_TRIM` | | 直线行驶不跑偏时的中位补偿 | |
| `SERVO_HALF_RANGE` | | 轮子打满但拉杆不顶死的最大值 | |
| `MOTOR_REVERSE` / `SERVO_REVERSE` / `ENCODER_DIR` | | 方向核对，反了改配置不要拆线 | |

**整车基础数据**

| 项目 | 数值 |
|---|---|
| 整车质量 | g |
| 轴距 / 轮距 | mm / mm |
| 轮径 | mm |
| 减速比 | |
| 满电电压 / 单场比赛后电压 | V / V |

---

## 二、适应性路段测试（Day3 下午）

### 绕桩

| 轮次 | 改了什么参数 | 改前 → 改后 | 通过时间 | 现象（推头/打滑/转向滞后） | 结论 |
|---|---|---|---|---|---|
| 1 | 基准（不改） | — | | | |
| 2 | | | | | |
| 3 | | | | | |

### 起伏颠簸路面

| 轮次 | 改了什么参数 | 改前 → 改后 | 通过时间 | 现象（弹跳/失控/托底） | 结论 |
|---|---|---|---|---|---|
| 1 | 基准（不改） | — | | | |
| 2 | | | | | |

> 手册要求此段**采集加速度计震动数据**。⚠️ 注意：GT_TEST 这一版**没有 IMU 驱动**
> （SPI3 上的 LSM6DSR 未实现，遥测帧里加速度字段恒为 0）。
> 应对方案二选一：① 找主办方要 IMU 驱动或确认是否有完整版固件；
> ② 用编码器速度的波动幅度作为替代指标记录（速度抖动越大 = 弹跳越严重）。
> 无论选哪个，都要在报告里写清楚为什么这么做。

### 8 字回转

| 轮次 | 改了什么参数 | 改前 → 改后 | 单圈时间 | 现象 | 结论 |
|---|---|---|---|---|---|
| 1 | 基准（不改） | — | | | |
| 2 | | | | | |

---

## 三、完整赛道圈速迭代

> 每轮固定跑 3~5 圈，取**最快单圈**和**平均圈速**。只看最快单圈容易被一次幸运圈误导。

| 轮次 | 时间 | 改动参数 | 改前 → 改后 | 最快单圈 | 平均圈速 | 是否保留 | 备注 |
|---|---|---|---|---|---|---|---|
| 基准 | | — | — | | | ✅ | 第一版开环直通 |
| 2 | | | | | | ☐ | |
| 3 | | | | | | ☐ | |
| 4 | | | | | | ☐ | |
| 5 | | | | | | ☐ | |
| 6 | | | | | | ☐ | |
| 7 | | | | | | ☐ | |
| 8 | | | | | | ☐ | |

**调参优先级建议**（从影响最大的开始试）

1. `GEAR_SCALE_TABLE` 高档系数 —— 直道极速
2. `MOTOR_SLEW_PER_MS` —— 太小起步肉，太大出弯打滑
3. `SERVO_HALF_RANGE` —— 转向行程，影响最小转弯半径
4. `SPEED_FILTER_ALPHA` —— 只影响遥测好不好看，不影响手感，最后再动
5. 开环 → 闭环 PID —— 收益最大但风险也最大，务必先有基准圈速再动

---

## 四、三人驾驶成绩（Day3 晚，用于定耐力赛排班）

| 车手 | 练习圈数 | 最快单圈 | 平均圈速 | 稳定性（撞墙次数/10 圈） | 建议赛段 |
|---|---|---|---|---|---|
| | | | | | |
| | | | | | |
| | | | | | |

---

## 五、换胎进站演练

| 演练次数 | 总耗时 | 卡在哪个环节 | 改进措施 |
|---|---|---|---|
| 1 | | | |
| 2 | | | |
| 3 | | | |

**目标：< 20s。** 耐力赛两次进站，比别人每次快 30 秒就是一分钟的巨大优势。

---

## 六、故障与隐患台账

| 日期 | 部位 | 现象 | 处理 | 是否复发 |
|---|---|---|---|---|
| | | | | |
| | | | | |

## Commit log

2026-09-05 黑客松冠军车机械设计资料开源
    STL(后轴承座重设计/轮辐盘)、机械结构说明书 PDF、团队文档模板、
    齿轮传动计算器。固件基于主办方模板故不含在内。
    [rear_axle_mount_redesign.stl, wheel_plate_x4.stl]
2026-09-05 .gitattributes 标记二进制文件, 防止 PDF/STL 被换行符转换损坏
2026-09-25 补全前桥与后桥全套 STL
    之前只收录了后轴承座和轮辐盘, 补上桌面散落的其余 8 个文件:
    前桥最终定稿打印板(8/28 reprint_plate)、后桥载架打印板、
    后驱动支架、配合接口基准件、比赛日凌晨 2:10 的抢修托架,
    以及 iterations/ 下被取代的历史版本(前桥 v1/v5、后轴承座旧版)。
    经 md5 比对, 已发布的 rear_axle_mount_redesign 与桌面 brandnew.stl
    是同一文件, 未重复收录。README 增加零件清单表与总览渲染图。
    [front_plate_final_0828.stl, front_plate_v1_0827.stl, front_plate_v5_0827.stl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]
2026-09-25 移除三个零件, 更新零件清单与总览图
    删除 mate_interface_reference / rear_axle_carrier_print_plate /
    rear_drive_mount, 同步更新 README 零件表和 parts_gallery 渲染图。
    [mate_interface_reference.stl, rear_axle_carrier_print_plate.stl, rear_drive_mount.stl]
